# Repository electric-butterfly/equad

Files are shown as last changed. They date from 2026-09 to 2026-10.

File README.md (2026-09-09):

# eQuad

Electric conversion of a 2012 Suzuki King Quad 400 (LT-A400F), retaining the standard
shaft drivetrain and replacing the engine and CVT with a PMSM motor, a 26S2P lithium pack
and a Fardriver controller.

The vehicle keeps both differentials, both propeller shafts and the selectable 4WD front
end. An intermediate drive replaces the engine, transmission and transfer case, taking the
motor's output down to propeller-shaft speed and splitting it fore and aft.

## Duty

A working farm quad in Far North Queensland. It has to tow, it will spend its life in
heat, and it is the first build of a conversion approach intended to carry across to other
off-road machines — quads, side-by-sides, buggies and small ride-ons.

That duty sets the priorities: continuous thermal capability and low-speed tractive effort
ahead of top speed, and a battery box design that repeats across builds rather than one
tailored to this frame alone.

**Top speed target is 60–70 km/h flat out.** Range modes come from the controller's three
digital speed inputs, which select between three parameter maps.

---

## Current focus — the modelling workflow

The immediate objective is not the vehicle. It is a repeatable, AI-supported 3D modelling
workflow that turns a scan of the donor quad into Fusion or SolidWorks models good enough
to hand a fabricator for final manufacturing design and setup.

Everything downstream depends on it. The intermediate drive, the battery and switchgear
boxes and the cooling system are all packaging problems on a machine whose geometry exists
only as a scan and a set of physical parts.

### The workflow, end to end

| Stage | Output |
| --- | --- |
| Capture | Artec scan of the complete vehicle (held) |
| Condition | Decimated, hole-filled mesh aligned to a vehicle datum |
| Reference | Mesh imported to CAD as a non-parametric backdrop |
| Interface capture | Parametric solids for mounting faces, frame rails and shaft flanges only |
| Design | New assemblies modelled against those interfaces |
| Handover | STEP plus dimensioned drawings, toleranced at the interfaces |

The scan is a backdrop, not a model. Only the surfaces a new part actually touches get
reverse-engineered into parametric geometry; the rest stays as mesh. That keeps the CAD
tractable and puts the tolerance discussion exactly where the fabricator needs it.

### Where AI carries load

- Mesh conditioning and datum alignment driven as scripted, repeatable steps rather than
  by hand in a GUI.
- Fusion API (Python) and SolidWorks API scripting to generate parametric features from
  captured interface geometry.
- Maintaining a single parameter table — ratios, envelopes, centre distances — as the one
  source of truth that both the CAD and this repository read from.
- Extracting and cross-checking dimensions against the supplier datasheets and the Suzuki
  shop manual, so any number in the model can be traced back to a document.

### Source geometry

Two Artec exports of the complete vehicle:

| File | Triangles | Size |
| --- | --- | --- |
| King Quad 400 Full Res.stl | 35 074 344 | 1.75 GB |
| King Quad 400 Low Res.stl | 1 844 914 | 92.2 MB |

Both are valid binary STL. The low-res mesh bounds a volume of 2093 × 1850 × 1125 mm,
which places it in millimetres at roughly life size against the vehicle's 2060–2160 mm
overall length and 1145 mm overall height.

The 1850 mm intermediate extent is well beyond the vehicle's 1200 mm overall width, so the
mesh is either rotated within its own frame or carries geometry captured beyond the quad
itself. Establishing a vehicle datum — and trimming to it — is the first stage of
conditioning.

Scan data lives in the project drive, not in this repository.

### Design packages

**Intermediate drive.** The load-bearing item. A single cross-shaft carrying output stubs
for the standard front and rear propeller shafts, driven from the motor, with tension taken
up by the motor mount. It has to reproduce the propeller shaft spline interfaces exactly,
set the centre distance for the chosen drive, and shed mud and debris.

Chain is the working assumption over toothed belt, on the fabricator's recommendation:
higher torque capacity, tolerant of an unsealed housing, smaller footprint, durable in a
rugged environment, and length adjustable and breakable for installation. The costs are
noise, lubrication and maintenance, and higher rotating inertia.

The shop manual gives service data for the output shafts — bevel gear backlash
0.03–0.15 mm, output and bevel gear nuts at 100 N·m — but no spline or flange dimensions.
Those interfaces have to come from measurement of the parts and from the scan.

**Battery boxes.** Two packs in an inverted V, one either side, leaving a channel down the
centre for the front propeller shaft. The channel doubles as the cooling duct, so the two
packages are dimensionally coupled — cells set the wall angle, and the duct sets the
minimum clear width between them.

The inverted V also puts pack mass low and outboard, which suits a machine that tows, and
it splits the pack into two enclosures that can carry their own contactor and fuse. Whether
the volume is really there is a scan question, not a paper one.

**Controller box.** An aluminium box in the fuel tank position holding the controller, the
AC and DC terminations and control wiring, with its base doubling as the duct roof and
heatsink. The relay-version BMS drives remote contactors, so no main current passes through
box electronics.

Sealing it against mud and water means everything inside loses its own path to air. Busbar
and terminal joint losses at pack current are tens of watts with nowhere to go but the base
plate already carrying the controller. Solar gain on an aluminium box in the open in FNQ is
worth a thought too.

**Switchgear box.** Separate. Contactors, fuses, fuse holders, pre-charge and the DC-DC
converter. Two packs with two-pole isolation each accounts for the four main contactors;
pre-charge needs a fifth, and six were purchased.

**Cooling.** Forced air. The motor is air-cooled and is the continuous bottleneck; the
controller is natural-convection cooled and fully potted. Neither will look after itself
under a sustained tow in the heat, and natural airflow at crawl speed is close to zero —
which is exactly when the load is highest.

The donor supplies most of the hardware. It carries a cooling fan on a bracket at the oil
cooler, and the LT-A400 also has moulded V-belt cooling ducts running from a high intake
down into the centre of the machine — the same channel the battery box is aiming at, and
already routed the way it is because grass seed and mud are the enemy of a low intake.
Both the fan mounting and the duct geometry are in the scan and are worth capturing rather
than redesigning.

Fan control comes from the motor's KTY83-122 probe and controller temperature, not the
stock thermo-switch, which closes at about 120 °C engine oil temperature — at or past the
motor's own working ceiling. Run-on after shutdown matters more on an air-cooled motor than
it did on the engine, because a hot motor with the machine stopped has no airflow at all.

### Duct and fan sizing

Design point: 35 °C ambient at 750 m, which gives an air density of 1.047 kg/m³. Air enters
at the centre channel, passes the controller, then the motor, and rejects to the rear.
Controller first is correct — it is the temperature-sensitive item, rated to 55 °C ambient
against a 120 °C motor.

| Duty | Motor loss | Controller loss | Total |
| --- | --- | --- | --- |
| 4.0 kW shaft | 444 W | 91 W | 535 W |
| 7.5 kW shaft | 833 W | 170 W | 1003 W |

Carrying 1000 W on a 15 K air temperature rise needs **64 L/s, about 140 cfm**. The lighter
duty needs 34 L/s. Duct section then sets velocity, and velocity sets both heat transfer
and fan work:

| Duct | Velocity | Pressure drop | Fan power at 12 V |
| --- | --- | --- | --- |
| 200 × 120 mm | 2.7 m/s | 30–56 Pa | 1.2 A |
| 150 × 100 mm | 4.3 m/s | 76–143 Pa | 3.0 A |
| 120 × 80 mm | 6.7 m/s | 186–349 Pa | 7.4 A |

**150 × 100 mm is the sensible compromise.** Wider and the air moves too slowly to pick the
heat up; narrower and fan power climbs faster than the heat transfer it buys.

The fan has to hold pressure, not just move free air. At 64 L/s against 150 Pa the air
power is only 9 W, but at realistic fan efficiency that is around 3 A at 12 V — comfortable
against the 30 A DC-DC. A centrifugal automotive cabin blower or a high-static axial suits;
a cheap muffin-style axial stalls well below this pressure. Whether the donor's oil-cooler
fan is pressure-capable enough is not established.

### The controller needs fins

The controller is a sealed, potted brick. Its heat leaves through the aluminium baseplate,
189 × 122 mm, so it bolts baseplate-down onto whatever does the rejecting. The potted body
itself is not a useful radiating surface, and putting the brick in the airstream achieves
little beyond obstructing the duct.

Mounting it to the duct wall does not work. At 4.3 m/s the inner face sees about
18 W/m²K and the outer face sits in still air under the machine at perhaps 6 W/m²K. On a
150 mm wide duct that yields:

| Wall panel | Wetted area | Heat rejected |
| --- | --- | --- |
| 150 × 300 mm | 0.045 m² | 25 W |
| 150 × 400 mm | 0.060 m² | 33 W |
| 150 × 600 mm | 0.090 m² | 49 W |

Against 170 W the required bare wall is 0.31 m² — a duct 2.1 m long. Not available.

A plate spreads heat poorly at that scale, too. Acting as a fin, a 6 mm aluminium plate
runs at 73% efficiency 200 mm from the source and 45% at 400 mm; 15 mm plate reaches 87%
and 64%. The far corners of a large plate contribute much less than their area suggests.

### Switchgear box as the heatsink

The arrangement: an aluminium box in the fuel tank position, controller bolted flat to the
box base, and that base forming the roof of the duct. Welded sheet strips hang down from it
into the airstream. The tank position gives roughly the right envelope — the stock tank is
16.0 L including 2.9 L reserve — and the box also carries the BMS and terminals.

Welded strips suit this better than an extrusion. Thick strips conduct well, so fin
efficiency stays high, and the wide pitch that welding forces keeps pressure drop and
fouling down — both of which matter more here than packing density.

Fin efficiency, weldable alloy at about 150 W/m·K:

| Strip thickness | 40 mm high | 60 mm high | 80 mm high |
| --- | --- | --- | --- |
| 3 mm | 0.96 | 0.91 | 0.86 |
| 4 mm | 0.97 | 0.93 | 0.89 |
| 6 mm | 0.98 | 0.96 | 0.92 |

Sizing with 4 mm strips at 20 mm pitch — seven fins across the 150 mm duct:

| Fin height | Length | Wetted area | Rejected | Duct blockage |
| --- | --- | --- | --- | --- |
| 40 mm | 300 mm | 0.199 m² | 108 W | 7% |
| 40 mm | 400 mm | 0.266 m² | 144 W | 7% |
| 60 mm | 300 mm | 0.272 m² | 147 W | 11% |
| 60 mm | 400 mm | 0.363 m² | 196 W | 11% |

**60 mm strips over 350–400 mm covers the 170 W worst case with margin**, at about 11%
blockage — a small velocity rise and a modest pressure penalty.

The base plate has to spread heat from the controller's 189 × 122 mm footprint out to the
far fins. At 8–10 mm it runs 0.82–0.85 efficient 150 mm beyond the controller; 6 mm drops
to 0.78. Ten millimetres is the sensible base, and it welds and stiffens well. Fins
directly beneath the controller work at full effect, so they earn their length there first.

**Open input:** the manual gives the controller a working temperature of −30 to +55 °C
without saying whether that is ambient or baseplate. If it is ambient and the baseplate may
run to 85 °C, the temperature difference goes from 30 K to 50 K and the required area falls
from 0.39 m² to 0.24 m². That single answer changes the heatsink by a factor of 1.6 and is
worth getting from Fardriver before the switchgear box is drawn.

The motor is the easier problem because it tolerates a much larger temperature difference,
but at 0.3–0.6 m² of case area it is still marginal at the 7.5 kW duty. If the case does
not provide that, the practical continuous rating in this installation is nearer 4 kW than
7.5 kW — which is a reason to gear for tractive effort rather than speed.

**Layout.** Mass distribution, ground clearance and service access across the whole
vehicle.

---

## Vehicle

2012 Suzuki King Quad 400, LT-A400F — automatic (V-belt CVT), 2-speed transfer with
reverse, selectable 4WD, shaft drive front and rear.

| | |
| --- | --- |
| Overall length | 2060–2160 mm |
| Overall width | 1200 mm |
| Overall height | 1145 mm |
| Wheelbase | 1220 mm |
| Front / rear track | 880 / 900 mm |
| Ground clearance | 250 mm |
| Seat height | 840 mm |
| Dry mass | 252–275 kg |
| Tyres | AT25 × 8-12 front, AT25 × 10-12 rear |

Stock driveline ratios, from the shop manual:

| | LT-A400 (auto) |
| --- | --- |
| Primary (CVT) | 2.938 – 0.813 variable |
| Secondary | 2.730 (42/19 × 21/17) |
| Final drive, front and rear | 3.600 (36/10) |
| Transfer — low / high / reverse | 2.500 / 1.375 / 2.125 |

The conversion deletes the engine, CVT and transfer case. Only the 3.600 final drive
survives, and reverse moves to the controller and a DNR selector.

## Drivetrain sizing

The V3 motor carries a 1:2.35 reduction inside it, so the motor's rotor speed and the
speed presented to the intermediate drive are not the same number. Ratios below are stated
from the rotor.

| | |
| --- | --- |
| Motor maximum speed | 7000 rpm |
| Internal gearbox | 2.350 |
| Motor output shaft, maximum | 2979 rpm |
| Motor output sprocket | 428 chain, 14–16 teeth |
| Final drive | 3.600 |
| Rolling circumference | 1.995 m (AT25, 635 mm diameter) |

### Selecting the intermediate ratio

Road speed and tractive effort trade directly against each other through this one ratio.
Candidates on standard 428 sprockets, against the 60–70 km/h target:

| Drive | Driven | Ratio | Top speed | Peak effort | Continuous effort |
| --- | --- | --- | --- | --- | --- |
| 15 | 21 | 1.400 | 70.7 km/h | 2381 N | 508 N |
| 14 | 20 | 1.429 | 69.3 km/h | 2430 N | 518 N |
| 15 | 22 | 1.467 | 67.5 km/h | 2494 N | 532 N |
| 14 | 21 | 1.500 | 66.0 km/h | 2551 N | 544 N |
| 15 | 23 | 1.533 | 64.6 km/h | 2608 N | 556 N |
| 14 | 22 | 1.571 | 63.0 km/h | 2673 N | 570 N |
| 15 | 24 | 1.600 | 61.9 km/h | 2721 N | 581 N |
| 14 | 23 | 1.643 | 60.3 km/h | 2794 N | 596 N |

Effort figures are total at the axles on a 635 mm tyre, from 150 N·m peak and 32 N·m
continuous at the motor output. The band is narrow — 60 km/h buys only 17% more tractive
effort than 70 km/h — so the choice can be made on packaging and sprocket availability
rather than agonised over. Something near 14/21 or 15/22 sits mid-target.

For reference, the originally sketched 2:1 gives 49.5 km/h with 3402 N peak.

### Control mapping

Three digital speed inputs select three parameter maps. The intent is distinct throttle
and response curves per map — a genuine low-speed crawler mode with a softened throttle
curve and a lower ramp rate, a general working map, and an unrestricted map.

Crawl control was the part of the deleted low range that mattered most day to day, and
mapping recovers it. What mapping cannot recover is thermal headroom under sustained load,
which stays a function of the mechanical ratio alone. That keeps sustained towing duty —
not crawl feel — as the argument for the lower end of the ratio band.

The wiring inputs are confirmed in the controller manual: high gear / low gear, reverse and
cruise. Which parameters are per-map rather than global is not documented in the material
held, and it needs establishing before the crawler map can be specified.

## Powertrain

**Motor** — SIAECOSYS QS138 90H V3, PMSM mid-drive with integrated single-stage gearbox.

| | |
| --- | --- |
| Rated voltage | 72 V |
| Rated power | 4000 W |
| Peak power | 11–13.5 kW |
| Motor speed, rated / maximum | 4800 / 7000 rpm |
| Internal gear ratio | 1:2.35 |
| Output | 428 chain sprocket |
| Torque at output, rated / maximum | 32 / 150 N·m |
| Rated current | 60 A |
| Maximum bus current | 200 A |
| Maximum efficiency | 90–93% |
| Magnet | 90 mm, 5 pole pairs |
| Sensor | Single hall set |
| Mass | 14.5–16.6 kg |
| Protection | IP67 |

Reseller figures vary — continuous power is quoted anywhere from 4 kW to 7.5 kW and peak
from 11 kW to 20 kW. The torque figures are internally consistent with the gearbox ratio,
so they are the ones to design against.

**Controller** — Fardriver ND961000, NS48 family.

| | |
| --- | --- |
| Rated voltage | 96 V |
| Bus current | 450 A |
| Phase current | 1000 A |
| Rated power | 5.0–9.0 kW |
| Envelope | 189 × 122 × 54.7 mm |
| Cooling | Natural convection, fully potted |
| Operating temperature | −30 to +55 °C |
| Interfaces | CAN, RS485, one-wire, analogue |

**Battery** — CALB L148N58A prismatic lithium-ion, 26S2P.

| Cell | |
| --- | --- |
| Nominal capacity | 58 Ah at 1C |
| Working voltage | 2.75–4.35 V above 0 °C |
| Internal resistance | 0.60–0.80 mΩ at 1 kHz, 70% SOC |
| Continuous discharge | 1C (58 A) at 20–40 °C |
| Pulse discharge | 450 A for 10 s below 50 °C |
| Recommended SOC window | 5–97% |
| Mass | 926 ± 20 g |
| Envelope | 148.24 × 26.66 × 105.9 mm |
| Terminal spacing | 110.6 mm |
| Case | Aluminium alloy |

| Pack (26S2P) | |
| --- | --- |
| Nominal | 96.2 V |
| Range | 71.5–113.1 V |
| Capacity | 116 Ah |
| Energy | 11.16 kWh, 10.04 kWh at 90% DoD |
| Continuous | 116 A, 11.2 kW |
| Cell mass | 48.2 kg for 52 cells |

Charge current is temperature-limited: 1.2C peak at 20–45 °C, falling to 0.2C at 0–10 °C
and disallowed below −20 °C. Regenerative braking is limited by state of charge as well as
temperature — 5C for 10 s at 80% SOC and 20–40 °C, and not permitted at all above 95% SOC.
Both constraints belong in the BMS configuration, not only in the documentation.

**BMS** — ANT 21S–30S, 24–112 V, 400 A / 1000 A, with CAN customisation.

**Switchgear** — TE Kilovac EV200HAANA sealed contactors, SPST-NO, 500 A, 9–36 V DC coil.
Littelfuse JLLN Class T fuses with LSCR holders.

**Auxiliary** — 48–120 V to 12 V, 30 A, 400 W DC-DC converter.

**Charging** — two chargers held. Output voltage and current are unconfirmed and no
charger appears in the BOM.

## CAN architecture

The Fardriver CAN protocol is SAE J1939-21 over CAN 2.0B at 500 kbit/s, PDU2 format.

| Node | Source address |
| --- | --- |
| BMS | 1 |
| Motor controller | 2 |
| Instrument | 3 |
| Central control | 4 |

Termination is not uniform across the bus. The controller carries its own 120 Ω and a
non-isolated transceiver; the instrument needs an isolated transceiver and provides a
120 Ω; the BMS provides no resistor and references the bus to battery negative. The harness
design has to respect that asymmetry.

## Reference library

Held in the project drive alongside the scans:

- Suzuki King Quad 400 LT-A400F / LT-F400F shop manual, 2008–2014
- CALB L148N58A cell specification and dimensioned drawing, plus superseded cell
  candidates from CATL, CALB and JMRI
- Fardriver controller manual, tuning guide, NS48 and S60 datasheets, CAN18 protocol
- TE Kilovac contactor and Littelfuse JLLN datasheets
- EB-Quad BOM and gear ratio calculator
- Drive pulley concept sketch
- Supplier contracts and invoices

## Open engineering questions

**Cell continuous rating.** The BOM records these cells at 8C and 268 A continuous. The
datasheet allows 1C continuous — 58 A per cell, 116 A at pack level — with 8C available
only as a 450 A, 10-second pulse. The supplier listing reads the same way, so the 8C
figure is a misreading rather than a supplier claim.

It does not force a redesign. The motor is the continuous bottleneck, not the pack:

| Limit | Current at 96.2 V | Power |
| --- | --- | --- |
| Motor, continuous | 42–78 A | 4.0–7.5 kW |
| Pack, continuous (1C) | 116 A | 11.2 kW |
| Motor, maximum bus | 200 A | 19.2 kW |
| Pack, 10-second pulse | 900 A | — |
| Controller bus limit | 450 A | 43.3 kW |

The pack comfortably outruns what the motor can absorb continuously, and its pulse
capability sits well above the motor's peak. What the 8C figure does need to change is the
BMS configuration — set discharge limits from the datasheet, not the BOM — and any future
sizing calculation that inherits it.

**Voltage margin.** The binding limit is the controller, not the fuse. The ND961000's peak
battery voltage is 115 V; a pack charged to 4.35 V per cell reaches 113.1 V — under two
volts of headroom. The JLLN fuse is the looser constraint at 125 V DC. Capping charge
voltage below 4.35 V per cell costs a little capacity and buys cycle life anyway, and is
the cheaper fix than dropping to 25S.

**Fuse sizing.** An 800 A element sits far above both the 450 A controller bus limit and
the 116 A cell limit, so it protects against a short circuit and nothing else. Overload
protection has to come from the BMS and controller.

**Contactor datasheet.** The parts held are EV200HAANA; the datasheet on file is for the
LEV200 series. The EV200 datasheet is the one to design the switchgear box against.

**Intermediate ratio.** Narrowed to 1.40–1.64 by the 60–70 km/h target, but not yet
fixed. The remaining input is packaging: sprocket diameters and the centre distance they
imply have to fit the space the engine vacates, which is a scan question. This is the
last drivetrain number the fabricator needs.

**Motor speed limit.** Rated voltage is 72 V; the pack is 96.2 V nominal and 113.1 V at
full charge. Speed scales with voltage, so at full charge the motor would run past its
7000 rpm mechanical ceiling before flux weakening is asked for. The controller's rpm limit
has to be set deliberately, not left at default.

**Thermal headroom.** The motor is air-cooled and it is the continuous bottleneck, on a
machine that tows in FNQ heat. Forced air is the plan; what is not yet settled is the duct
routing, whether the stock fan moves enough air for the new heat load, and how the
controller derates on temperature. All three want answering before the layout is fixed
rather than after the first hot tow.

**ANT CAN protocol.** The BMS was ordered with CAN customisation specifically to join the
J1939 bus, and the supplier confirmed they can provide the protocol document. It is not in
the reference library. Without it the BMS cannot be integrated, and the harness and dash
design cannot be closed out.

**Pre-charge.** Required. Two distinct inrush problems exist in this architecture and only
one of them is solved by matching pack voltages.

Matching the two packs before paralleling controls pack-to-pack circulating current, and
that plan is sound. It does nothing for the controller's DC bus capacitors, which sit at
zero volts every time the system is switched on regardless of how well the packs agree.
Closing a main contactor straight onto them is a capacitor charging event limited only by
loop resistance.

Peak inrush is set by loop resistance alone — capacitance governs how long it lasts, not
how high it goes. The pack's own internal resistance dominates the loop at 9.1 mΩ for
26S2P, from the cell datasheet's 0.6–0.8 mΩ:

| Added cable, contactor and ESR | Peak inrush |
| --- | --- |
| 5 mΩ | 8021 A |
| 10 mΩ | 5921 A |
| 20 mΩ | 3887 A |
| 40 mΩ | 2303 A |

Even with no external resistance at all the pack can only deliver 12 429 A, and holding
inrush to the contactors' 2000 A interrupt rating would need 56.5 mΩ of added loop —
six times the pack's own resistance, which a short heavy-cable HV loop will not provide.
The conclusion holds across the whole plausible range: making a main contactor onto a
discharged bus welds contacts, and not necessarily the first time, which is why the
omission surfaces late.

A resistor across one pack's main contactor, switched by a pre-charge contactor, fixes it.
Sequence is pre-charge, confirm bus voltage has risen to pack voltage, close the pack mains
onto an already-charged bus, then drop pre-charge. The second pack then closes onto a bus
already at its own voltage, which is where the manual voltage matching does its work.

**Sizing the resistor needs the bus capacitance, which is not published.** It is absent
from the controller manual, the NS48 datasheet and the reseller listings. It sets both the
pre-charge duration (5RC to 99%) and the pulse energy the resistor must absorb, which is
½CV² per closure regardless of resistor value. Measuring it settles both: charge the bus
through a known high resistance from a bench supply and time the rise to 63%.

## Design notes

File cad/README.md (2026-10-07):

# Battery box CAD

All parameters come from `params.toml`. Run every script from the repo root.

| Script | venv | Run order | What it builds |
|---|---|---|---|
| `cell.py` | `.venv-cad` | 1 | The cell and the 26-cell block; `--report` writes `cell-report.md` |
| `enclosure.py` | `.venv-cad` | 2 | The enclosure, lid, internals, fuse bay and cable exits |
| `assembly.py` | `.venv-cad` | 3 | Two boxes on the datum, motor placeholder, keep-out, `placement.json` |
| `clearance.py` | `.venv-mesh` | 4 | Placement evaluation, the sweep, section renders |
| `mounts.py` | `.venv-mesh` | 5 | Frame primitives within reach of the placed box |
| `viewer.py` | `.venv-cad` | 6 | `viewer.html` and `sam-battery-boxes.html` |
| `fusion_pack.py` | `.venv-cad` | 7 | `datum-marker.step` and `fusion-import.html` |

Every script resolves the repo root with `git rev-parse --show-toplevel`, loads `cad/params.toml`,
writes only to `data/cad/` and `docs/thrifty/2026-09-15-battery-boxes/artefacts/`, and refuses to
run if a named input is missing. `common.py` reads `freecad_cmd` from
`pipeline/config.local.toml` for the STEP round-trip check; no other script reads that file.

```
.venv-cad/Scripts/python cad/cell.py
.venv-cad/Scripts/python cad/enclosure.py
.venv-cad/Scripts/python cad/assembly.py
.venv-mesh/Scripts/python cad/clearance.py
.venv-mesh/Scripts/python cad/mounts.py
.venv-cad/Scripts/python cad/viewer.py
.venv-cad/Scripts/python cad/fusion_pack.py
```

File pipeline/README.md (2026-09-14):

# Pipeline

Condition, crop, segment and fit the King Quad scan against the vehicle datum. See
`docs/thrifty/2026-09-14-scan-pipeline/plan.md` section 4 for the full contract.

## Setup

1. Create the mesh venv and install its pins:
   ```
   python -m venv .venv-mesh
   .venv-mesh/Scripts/python -m pip install -r pipeline/requirements-mesh.txt
   ```
2. Install CloudCompare (`winget install --id CloudCompare.CloudCompare --exact`) and MeshLab
   (`winget install --id CNRISTI.MeshLab --exact`).
3. Copy `pipeline/config.example.toml` to `pipeline/config.local.toml` and fill in the absolute
   paths on this machine (scan files, `data_root`, `CloudCompare.exe`, `FreeCADCmd.exe`).
   `config.local.toml` is git-ignored.

## Stages

| Script | Written by | Purpose |
|---|---|---|
| `pipeline/condition.py` | WP-03 | Clean the full-res scan, remove the floor, align to the ISO 8855 vehicle datum, write decimations and `datum.json`. |
| `pipeline/crop.py` | WP-04 | Cut the six named regions from `pipeline/crops.toml` into per-region meshes, point clouds and silhouettes. |
| `pipeline/segment.py` | WP-05 | Run CloudCompare RANSAC on each region's point cloud and write a primitive table per region. |
| `pipeline/fit.py` | WP-06 | Refine each accepted primitive on full-resolution points and write `interfaces.json` with residuals. |

Each script loads `pipeline/config.local.toml` via `pipeline/common.py`, resolves `data_root`
against the repo root, and refuses to run if a required key or file is missing. Run from the mesh
venv:

```
.venv-mesh/Scripts/python pipeline/condition.py
.venv-mesh/Scripts/python pipeline/crop.py
.venv-mesh/Scripts/python pipeline/segment.py
.venv-mesh/Scripts/python pipeline/fit.py
```

Every script takes `--stage-only` flags as documented in its own `--help`, and writes nothing
outside `data_root` and `docs/thrifty/2026-09-14-scan-pipeline/artefacts/`.

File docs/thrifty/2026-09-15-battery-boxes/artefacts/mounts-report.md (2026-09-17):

104 frame primitives within 120 mm of a placed battery box.

| id | kind | box | face | distance mm | support | rms |
|---|---|---|---|---|---|---|
| engine-bay/cyl/148 | cylinder | right | inboard | 1.1 | 4723 | 0.97 |
| engine-bay/plane/046 | plane | left | inboard | 1.6 | 2088 | 0.24 | *calliper before drilling*
| tank-mounts/cyl/064 | cylinder | left | inboard | 1.8 | 7256 | 0.82 |
| duct-route/cyl/092 | cylinder | left | inboard | 2.8 | 29471 | 0.94 |
| engine-bay/plane/014 | plane | left | inboard | 3.5 | 3225 | 0.14 | *calliper before drilling*
| engine-bay/plane/031 | plane | right | inboard | 4.7 | 2490 | 0.25 | *calliper before drilling*
| engine-bay/plane/053 | plane | right | inboard | 5.8 | 1632 | 0.17 | *calliper before drilling*
| engine-bay/plane/015 | plane | left | rear | 5.9 | 4148 | 0.48 | *calliper before drilling*
| engine-bay/plane/032 | plane | right | outboard | 6.7 | 1630 | 0.19 | *calliper before drilling*
| engine-bay/plane/064 | plane | right | front | 6.7 | 1560 | 0.19 | *calliper before drilling*
| engine-bay/plane/037 | plane | left | front | 7.0 | 1662 | 0.16 | *calliper before drilling*
| engine-bay/plane/010 | plane | right | outboard | 8.7 | 5446 | 0.27 | *calliper before drilling*
| engine-bay/plane/011 | plane | left | outboard | 9.0 | 5085 | 0.18 | *calliper before drilling*
| duct-route/cyl/159 | cylinder | left | inboard | 11.0 | 3398 | 0.56 |
| tank-mounts/cyl/046 | cylinder | right | inboard | 12.3 | 13836 | 0.41 |
| engine-bay/cyl/107 | cylinder | left | inboard | 13.0 | 24932 | 0.77 |
| engine-bay/cyl/028 | cylinder | right | outboard | 13.1 | 26024 | 0.29 |
| rear-flange/cyl/015 | cylinder | right | outboard | 13.1 | 25956 | 0.33 |
| duct-route/cyl/071 | cylinder | right | outboard | 13.5 | 39433 | 0.80 |
| engine-bay/cyl/016 | cylinder | right | outboard | 16.5 | 69197 | 0.30 |
| duct-route/cyl/011 | cylinder | right | outboard | 16.6 | 72681 | 0.57 |
| tank-mounts/cyl/033 | cylinder | left | inboard | 17.7 | 23476 | 0.61 |
| duct-route/cyl/070 | cylinder | left | outboard | 18.1 | 39185 | 0.69 |
| engine-bay/plane/013 | plane | left | inboard | 18.8 | 3426 | 0.23 | *calliper before drilling*
| engine-bay/cyl/050 | cylinder | right | outboard | 19.5 | 20271 | 0.59 |
| rear-flange/cyl/035 | cylinder | right | front | 19.9 | 16052 | 0.89 |
| engine-bay/cyl/038 | cylinder | right | outboard | 21.9 | 49672 | 0.86 |
| duct-route/cyl/009 | cylinder | left | outboard | 22.1 | 105370 | 0.96 |
| duct-route/cyl/056 | cylinder | left | outboard | 22.3 | 16570 | 0.72 |
| duct-route/cyl/051 | cylinder | left | outboard | 22.3 | 68784 | 0.43 |
| engine-bay/cyl/085 | cylinder | right | outboard | 22.9 | 12657 | 0.98 |
| duct-route/cyl/094 | cylinder | left | outboard | 23.3 | 17668 | 0.90 |
| engine-bay/plane/030 | plane | right | lid | 23.9 | 2601 | 0.57 | *calliper before drilling*
| duct-route/cyl/044 | cylinder | right | outboard | 24.3 | 19682 | 0.72 |
| duct-route/cyl/022 | cylinder | right | outboard | 24.4 | 19068 | 0.49 |
| engine-bay/cyl/120 | cylinder | right | outboard | 24.7 | 46304 | 0.41 |
| tank-mounts/cyl/076 | cylinder | right | inboard | 24.8 | 6719 | 0.76 |
| engine-bay/cyl/041 | cylinder | left | inboard | 25.1 | 26198 | 0.98 |
| duct-route/cyl/043 | cylinder | right | outboard | 25.1 | 14177 | 0.48 |
| duct-route/cyl/027 | cylinder | left | outboard | 25.2 | 42893 | 0.49 |
| duct-route/cyl/059 | cylinder | left | outboard | 25.2 | 33489 | 0.12 |
| duct-route/cyl/032 | cylinder | left | front | 26.0 | 6945 | 0.75 |
| duct-route/cyl/103 | cylinder | left | inboard | 26.7 | 4494 | 0.40 |
| engine-bay/plane/035 | plane | left | rear | 26.8 | 1791 | 0.27 | *calliper before drilling*
| engine-bay/plane/039 | plane | right | lid | 27.1 | 3048 | 0.54 | *calliper before drilling*
| engine-bay/cyl/024 | cylinder | left | rear | 29.6 | 50320 | 0.20 |
| engine-bay/plane/009 | plane | left | outboard | 29.6 | 4437 | 0.15 | *calliper before drilling*
| engine-bay/plane/022 | plane | right | lid | 29.7 | 2835 | 0.36 | *calliper before drilling*
| engine-bay/plane/021 | plane | right | outboard | 30.0 | 2775 | 0.21 | *calliper before drilling*
| duct-route/cyl/042 | cylinder | right | front | 30.4 | 4429 | 0.93 |
| engine-bay/cyl/070 | cylinder | left | inboard | 32.3 | 14785 | 0.39 |
| tank-mounts/cyl/070 | cylinder | left | inboard | 34.5 | 15843 | 0.71 |
| engine-bay/cyl/138 | cylinder | right | inboard | 35.1 | 29500 | 0.39 |
| engine-bay/plane/019 | plane | right | front | 39.5 | 4835 | 0.93 | *calliper before drilling*
| duct-route/cyl/102 | cylinder | right | front | 40.3 | 4810 | 0.88 |
| duct-route/cyl/058 | cylinder | right | floor | 41.2 | 25759 | 0.37 |
| duct-route/cyl/048 | cylinder | left | front | 46.6 | 6203 | 0.84 |
| engine-bay/plane/025 | plane | right | rear | 47.9 | 2476 | 0.38 | *calliper before drilling*
| engine-bay/plane/016 | plane | left | rear | 48.4 | 3090 | 0.18 | *calliper before drilling*
| engine-bay/cyl/018 | cylinder | right | floor | 50.3 | 89594 | 0.37 |
| engine-bay/cyl/029 | cylinder | right | floor | 51.1 | 89922 | 0.57 |
| front-flange/cyl/048 | cylinder | left | rear | 51.6 | 68129 | 0.37 |
| engine-bay/cyl/013 | cylinder | right | floor | 54.7 | 131305 | 0.86 |
| duct-route/cyl/003 | cylinder | right | floor | 55.9 | 133590 | 0.72 |
| engine-bay/plane/001 | plane | left | front | 56.4 | 14975 | 0.34 | *calliper before drilling*
| engine-bay/plane/034 | plane | left | front | 56.9 | 2008 | 0.48 | *calliper before drilling*
| engine-bay/plane/028 | plane | right | front | 58.8 | 2547 | 0.24 | *calliper before drilling*
| engine-bay/plane/040 | plane | right | front | 60.7 | 1563 | 0.31 | *calliper before drilling*
| engine-bay/plane/027 | plane | right | front | 60.8 | 1982 | 0.30 | *calliper before drilling*
| engine-bay/plane/043 | plane | right | rear | 65.6 | 2463 | 0.57 | *calliper before drilling*
| engine-bay/plane/017 | plane | left | inboard | 68.1 | 3577 | 0.60 | *calliper before drilling*
| engine-bay/cyl/147 | cylinder | right | rear | 74.4 | 5920 | 0.67 |
| engine-bay/plane/007 | plane | right | front | 75.7 | 6759 | 0.30 | *calliper before drilling*
| engine-bay/cyl/056 | cylinder | right | front | 76.3 | 27356 | 0.95 |
| rear-flange/cyl/007 | cylinder | right | front | 76.6 | 23854 | 0.54 |
| rear-flange/cyl/009 | cylinder | left | front | 78.0 | 27002 | 0.88 |
| engine-bay/cyl/020 | cylinder | left | front | 79.7 | 88221 | 0.99 |
| tank-mounts/cyl/009 | cylinder | right | inboard | 80.6 | 98132 | 0.88 |
| engine-bay/plane/029 | plane | right | lid | 82.3 | 2106 | 0.16 | *calliper before drilling*
| engine-bay/plane/054 | plane | right | lid | 86.4 | 1686 | 0.09 | *calliper before drilling*
| engine-bay/plane/024 | plane | right | front | 87.7 | 2889 | 0.17 | *calliper before drilling*
| engine-bay/plane/020 | plane | left | front | 88.1 | 2721 | 0.28 | *calliper before drilling*
| engine-bay/plane/036 | plane | right | rear | 89.3 | 1817 | 0.34 | *calliper before drilling*
| duct-route/cyl/007 | cylinder | right | inboard | 89.6 | 88571 | 0.81 |
| engine-bay/plane/033 | plane | left | front | 91.2 | 1931 | 0.20 | *calliper before drilling*
| rear-flange/cyl/014 | cylinder | right | front | 92.2 | 71436 | 0.62 |
| duct-route/cyl/015 | cylinder | left | inboard | 94.9 | 84561 | 0.91 |
| engine-bay/plane/061 | plane | left | lid | 97.9 | 1521 | 0.66 | *calliper before drilling*
| engine-bay/cyl/004 | cylinder | left | rear | 102.7 | 99050 | 0.51 |
| duct-route/cyl/031 | cylinder | left | rear | 105.5 | 117657 | 0.83 |
| engine-bay/cyl/014 | cylinder | right | rear | 106.3 | 78150 | 0.21 |
| engine-bay/plane/005 | plane | left | inboard | 106.8 | 5679 | 0.15 | *calliper before drilling*
| duct-route/cyl/024 | cylinder | left | rear | 108.4 | 51173 | 0.42 |
| rear-flange/cyl/060 | cylinder | right | front | 111.1 | 22287 | 0.48 |
| tank-mounts/cyl/114 | cylinder | right | inboard | 111.9 | 25376 | 0.50 |
| front-flange/cyl/010 | cylinder | right | rear | 112.8 | 107573 | 0.32 |
| rear-flange/cyl/069 | cylinder | left | front | 112.9 | 18714 | 0.51 |
| engine-bay/cyl/035 | cylinder | right | inboard | 114.4 | 46128 | 0.24 |
| tank-mounts/cyl/043 | cylinder | left | inboard | 115.5 | 42661 | 0.32 |
| engine-bay/plane/002 | plane | left | inboard | 115.8 | 13127 | 0.38 | *calliper before drilling*
| engine-bay/cyl/072 | cylinder | left | inboard | 115.8 | 40069 | 0.45 |
| duct-route/cyl/008 | cylinder | right | inboard | 117.3 | 72471 | 0.44 |
| duct-route/cyl/023 | cylinder | right | rear | 118.3 | 33475 | 0.78 |
| duct-route/cyl/006 | cylinder | left | inboard | 119.5 | 82146 | 0.36 |

The mounting concept: two locating pins on each box floor engaging bushes on brackets from the lower rails, and two tensioners at the top, inboard, pulling the box down onto the pins and reached from above so their mechanism is out of the mud. Bracket design is Sam's. The planes in the table were fitted by RANSAC at 0.15-0.35 mm RMS but did not pass the pipeline's refinement threshold (section 5.1); each row that is a plane carries the note "calliper before drilling".

Section 5.1's four named engine-mount planes:
- `engine-bay/plane/001` (support 14975, rms 0.34): 56.4 mm from the left box, nearest face front.
- `engine-bay/plane/007` (support 6759, rms 0.30): 75.7 mm from the right box, nearest face front.
- `engine-bay/plane/010` (support 5446, rms 0.27): 8.7 mm from the right box, nearest face outboard.
- `engine-bay/plane/011` (support 5085, rms 0.18): 9.0 mm from the left box, nearest face outboard.

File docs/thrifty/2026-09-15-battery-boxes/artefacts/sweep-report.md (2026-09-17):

This sweep tests the frame, the placeholder motor and the propeller-shaft keep-out only; plastics, foot boards, tank and seat are not in the scan.

Grid: 525 placements, 0 pass.

| X | lean | feasible Y | feasible Z | best min_frame |
|---|---|---|---|---|
| 693.2 | 72.0 | - | - | none feasible |
| 693.2 | 77.0 | - | - | none feasible |
| 693.2 | 82.0 | - | - | none feasible |
| 693.2 | 87.0 | - | - | none feasible |
| 693.2 | 92.0 | - | - | none feasible |
| 743.2 | 72.0 | - | - | none feasible |
| 743.2 | 77.0 | - | - | none feasible |
| 743.2 | 82.0 | - | - | none feasible |
| 743.2 | 87.0 | - | - | none feasible |
| 743.2 | 92.0 | - | - | none feasible |
| 793.2 | 72.0 | - | - | none feasible |
| 793.2 | 77.0 | - | - | none feasible |
| 793.2 | 82.0 | - | - | none feasible |
| 793.2 | 87.0 | - | - | none feasible |
| 793.2 | 92.0 | - | - | none feasible |

No placement in the swept grid passes all three tests.

[placement] defaults (x=743.2, y=39.2643, z=440.4765, lean_deg=82.0) are not a grid point in this sweep, so no exact-match row exists; see the nearest grid rows above.

Motor placeholder vs frame (not part of pass, evaluated once): min_frame=0.07 mm, points inside=41066.

chamfer would not help: not evaluated in this run.

Nothing in this grid clears the frame - every one of the 525 placements has real frame points
inside the box (inside_frame never reached 0). The least-bad point found, used for the
section-*-best.png renders below, is x=793.2, y=-50.0, z=465.0, lean=87.0: min_frame=0.56mm,
inside_frame=15580 points, min_motor=178.8mm, min_keepout=0.012mm. This is not a fit; it is the
smallest measured intrusion in the swept neighbourhood, shown so the owner can see how close
"close" actually is.

Section renders: section-yz-default.png, section-xz-default.png, section-xy-default.png (the
committed [placement] defaults); section-yz-best.png, section-xz-best.png, section-xy-best.png
(the least-bad point above).

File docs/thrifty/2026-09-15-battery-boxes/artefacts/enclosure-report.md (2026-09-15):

# Enclosure report

## Parameters used
| Section | Key | Value |
|---|---|---|
| enclosure | internal | [460.0, 300.0, 200.0] |
| enclosure | sheet | 3.0 |
| enclosure | lid_face | +Z |
| enclosure | lid_inset | 15.0 |
| enclosure | lid_bolt_d | 6.5 |
| enclosure | lid_bolt_pitch_max | 60.0 |
| enclosure | end_plate | 6.0 |
| enclosure | partition | 3.0 |
| enclosure | compression_plate | 6.0 |
| enclosure | compression_wall | outboard |
| enclosure | compression_pairs | 5 |
| enclosure | compression_rows_z | [30.0, 75.0] |
| enclosure | compression_screw_d | 8.0 |
| enclosure | compression_travel_min | 10.0 |
| enclosure | chamfer_front_top | 0.0 |
| electrical | fuses_per_box | 2 |
| electrical | fuse_envelope | [90.0, 45.0, 60.0] |
| electrical | headroom | 60.0 |
| electrical | cable_exit_face | inboard |
| electrical | cable_exit_d | [20.0, 20.0, 25.0] |
| electrical | cable_exit_z | 160.0 |

## Y layout
| Element | Y low | Y high |
|---|---|---|
| end plate | -150.0 | -144.0 |
| fuse bay | -144.0 | -114.34 |
| partition | -117.34 | -114.34 |
| compression plate | 119.94 | 125.94 |
| stack length | 263.94 | |
| travel | 24.060000000000002 | |

## Front-column spacer - finding
Section 4.5 specifies a spacer of thickness `p - partition` between the front column's last cell and the compression plate. The rows produced by `cell.block()` (and section 4.4's own worked numbers, e.g. the 24.06 mm travel figure) show the front column's last cell is already flush with the 9-cell columns' last cell - both are positioned by the same `y0 + p*slot` formula at slot = n_max - 1. The computed gap here is 0.0 mm, not `p - partition` (26.66 mm). Building the literal-thickness block would overlap the compression plate, which spans the full cavity width. No spacer solid is built; box.step therefore has 7 solids (not the 8 the done-when criterion names), and box-full.step has 33 (not 34). Logged as a finding for the owner, not fixed by guessing at intent.

## Hole tables
Lid bolt holes: 26
Grub-screw holes: 10 (5 stations x 2 Z rows), through the outboard wall
Cable exit holes: 3, through the inboard wall

## Fuse envelopes
2 envelopes, overrun = -80.0 mm (no overrun)

## Interference table
| A | B | Intersection volume (mm3) |
|---|---|---|
| body | lid | 0 |
| body | end_plate | 0 |
| body | partition | 0 |
| body | compression_plate | 0 |
| body | fuse_0 | 0 |
| body | fuse_1 | 0 |
| body | block | 0 |
| lid | end_plate | 0 |
| lid | partition | 0 |
| lid | compression_plate | 0 |
| lid | fuse_0 | 0 |
| lid | fuse_1 | 0 |
| lid | block | 0 |
| end_plate | partition | 0 |
| end_plate | compression_plate | 0 |
| end_plate | fuse_0 | 32400.0 |
| end_plate | fuse_1 | 32400.0 |
| end_plate | block | 0 |
| partition | compression_plate | 0 |
| partition | fuse_0 | 16200.0 |
| partition | fuse_1 | 16200.0 |
| partition | block | 0 |
| compression_plate | fuse_0 | 0 |
| compression_plate | fuse_1 | 0 |
| compression_plate | block | 0 |
| fuse_0 | fuse_1 | 0 |
| fuse_0 | block | 50436.000000000015 |
| fuse_1 | block | 35977.68000000001 |

## Headroom check
needed = 165.9, internal_z = 200.0, OK

## box-shell.stl
bbox 466.0 x 306.0 x 206.0, 12 triangles, reimport is_manifold = True

## STEP round-trip checks
freecad: 7 solids, 3186335.6216923 mm3 (build123d: 7 solids, 3186335.6216923017 mm3) OK
freecad: 33 solids, 13764437.700272448 mm3 (build123d: 33 solids, 13764437.70027245 mm3) OK

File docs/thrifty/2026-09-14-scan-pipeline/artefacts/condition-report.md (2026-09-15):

# Condition report

Faces: loaded 35074344, after fragments 35027805, after floor 31097206.

## Datum agreement against artefacts/datum-reference.json

Axis angle differences (deg): X 0.014, Y 0.047, Z 0.048 (accept under 0.5).
Translation differences (mm): [0.36, 0.06, 0.02] (accept under 5).

## Floor and symmetry

Floor: inliers fraction 0.1609, RMS 1.209 mm.
Symmetry: rotation from PCA 11.617 deg, final fitness 0.5389, final RMSE 3.177 mm.

## Rear axle housing

Left: r=24.35 y=273.0 z=296.8 rms=0.76
Right: r=25.42 y=-265.4 z=300.7 rms=0.75
X span between sides: 0.58 mm.

## Renders

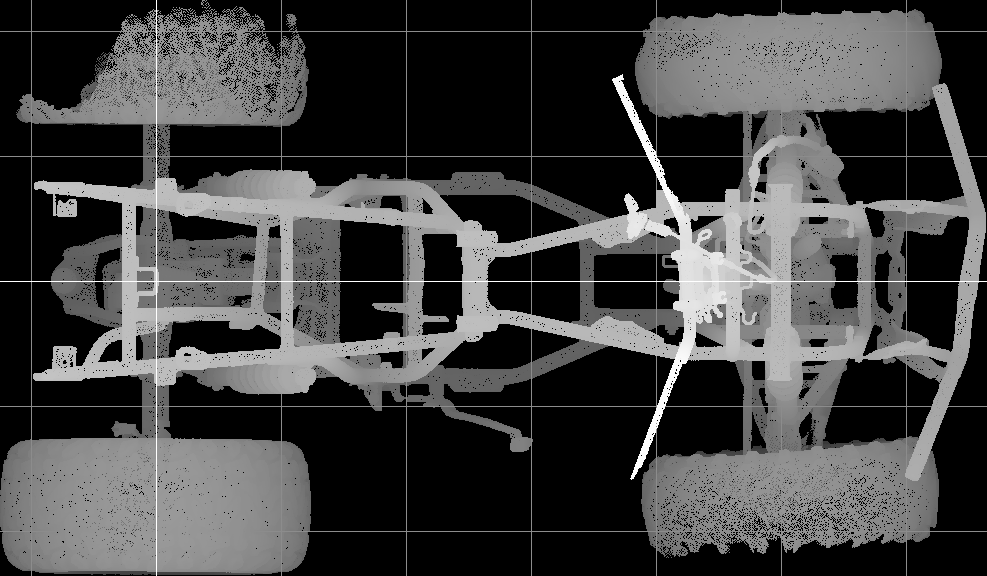
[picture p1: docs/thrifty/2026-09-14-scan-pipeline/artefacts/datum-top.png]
top


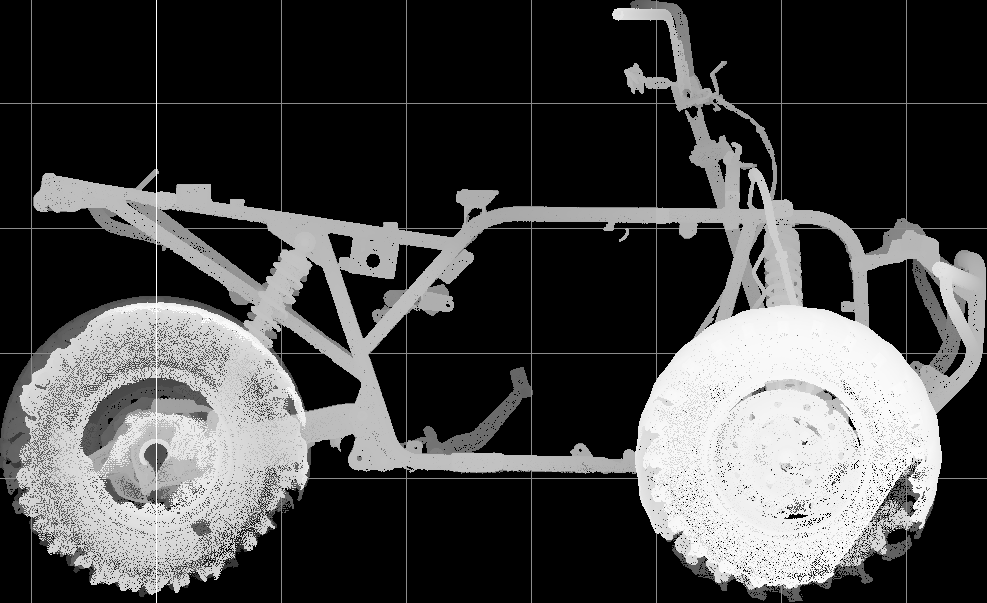
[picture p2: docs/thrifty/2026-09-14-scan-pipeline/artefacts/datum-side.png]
side


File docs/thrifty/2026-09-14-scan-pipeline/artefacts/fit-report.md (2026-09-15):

# Fit report — full-resolution refinement of RANSAC primitives

Per plan section 4.6. Candidates are RANSAC primitives that pass the section 4.5 acceptance rule
(cylinder: radius in a `tube_radii_mm` bracket and RANSAC rms under 1.2 mm; plane: RANSAC rms under
0.6 mm and support over 500). Each candidate is refined on full-resolution crop points within 3 mm
of the RANSAC surface (cylinders additionally bounded to the RANSAC primitive's own axial extent,
so the fit is not pulled in by unrelated points sharing the same infinite axis and radius). A
candidate is accepted when its refined rms is under 1.0 mm (cylinder) or 0.5 mm (plane); otherwise
it is written with `accepted: false` and a reason.

`tube_radii_mm` used: `[[11, 16], [17, 20], [22, 26], [26, 29]]` — the owner's
`pipeline/config.local.toml` extends the plan's default with a 26–29 mm bracket to admit the
rear-axle housing's left side. `CYLINDER_ACCEPT_RMS_MAX` is 1.0 mm in this run (`pipeline/fit.py`),
raised from the plan's original 0.8 mm. Neither change is reproducible from a fresh clone without
also setting `tube_radii_mm` locally, since `config.local.toml` is git-ignored by design.

## Per-region counts

| Region | Candidates | Accepted | Rejected |
|---|---|---|---|
| engine-bay | 206 | 32 | 174 |
| tank-mounts | 118 | 37 | 81 |
| front-flange | 142 | 26 | 116 |
| rear-flange | 85 | 11 | 74 |
| duct-route | 167 | 46 | 121 |
| rear-axle | 173 | 21 | 152 |
| **Total** | **891** | **173** | **718** |

## Rear-axle housing rows, in full

The two axle-housing cylinders identified by support are `rear-axle/cyl/001` (right side) and
`rear-axle/cyl/003` (left side).

| id | RANSAC radius | RANSAC support | Candidate? | Refined radius | Refined support | Refined rms | Accepted |
|---|---|---|---|---|---|---|---|
| rear-axle/cyl/001 | 24.97 mm | 21407 | yes | 25.601 mm | 79603 | 0.219 mm | true |
| rear-axle/cyl/003 | 27.03 mm | 24117 | yes (26–29 mm bracket) | 25.921 mm | 106842 | 1.940 mm | **false — refined rms 1.940 mm >= 1.0 mm** |

Widening the bracket got `cyl/003` into refinement, but it does not resolve to a clean cylinder:
its refined rms (1.940 mm) is well above even the relaxed 1.0 mm threshold, despite 106,842
supporting points. This is not a threshold or bracket problem — the real surface at that location
does not fit a constant-radius cylinder as well as the coarser RANSAC-stage estimate suggested,
which points to a physical feature near the housing (a flange, weld, or step) rather than a fitting
artefact. Confirming this needs a calliper or an individual rescan of the housing, not a further
threshold change.

## Ten worst residuals across all regions

| Region | id | Kind | Refined rms (mm) | p95 (mm) | Accepted |
|---|---|---|---|---|---|
| rear-axle | rear-axle/cyl/227 | cylinder | 8.019 | 14.644 | false |
| front-flange | front-flange/cyl/100 | cylinder | 8.019 | 13.794 | false |
| engine-bay | engine-bay/cyl/189 | cylinder | 6.378 | 11.597 | false |
| front-flange | front-flange/cyl/091 | cylinder | 5.690 | 11.245 | false |
| front-flange | front-flange/cyl/207 | cylinder | 5.657 | 10.209 | false |
| rear-axle | rear-axle/cyl/226 | cylinder | 5.646 | 9.303 | false |
| rear-flange | rear-flange/cyl/023 | cylinder | 5.545 | 9.154 | false |
| duct-route | duct-route/cyl/132 | cylinder | 5.323 | 9.125 | false |
| front-flange | front-flange/cyl/193 | cylinder | 5.149 | 8.158 | false |
| duct-route | duct-route/cyl/076 | cylinder | 4.759 | 9.780 | false |

All ten worst residuals are rejected cylinders; no accepted row (cylinder or plane) appears in this
list.

## The ~13 mm tube family

Widening the accept threshold to 1.0 mm was aimed at a cluster of well-supported ~13 mm-radius
cylinders that were rejected under the original 0.8 mm cutoff. Checking every cylinder with radius
12.5–15.5 mm and support over 50,000 points (81 candidates across five regions): 48 are now
accepted, 33 remain rejected, several with rms well over 1.0 mm (up to 2.29 mm). This is not one
tube gauge landing just past a threshold — it is a mix of genuinely clean fits and messier ones,
likely where the same tube family crosses welds or other features. The cleanest example is
`tank-mounts/cyl/001` (r 13.50 mm, rms 0.223 mm, support 181,694) — the candidate to calliper first
if confirming this tube gauge.

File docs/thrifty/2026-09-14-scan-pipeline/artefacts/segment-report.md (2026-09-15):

# Segment report — CloudCompare RANSAC per region

CloudCompare command as plan section 4.5, run once per region's `<region>_pts.ply` (full-res
crop points), full-res, not the 5 M-decimation reference cloud of section 5.5.

| Region | Primitives | Cylinders | Planes | Points assigned | 11–16 mm bracket | 17–20 mm bracket | 22–26 mm bracket |
|---|---|---|---|---|---|---|---|
| engine-bay | 347 | 193 | 154 | 70.3% | 71 (rms 0.65) | 9 (rms 0.58) | 0 |
| rear-axle | 477 | 314 | 163 | 61.5% | 42 (rms 0.56) | 13 (rms 0.59) | 10 (rms 0.58) |
| rear-flange | 150 | 92 | 58 | 70.7% | 31 (rms 0.51) | 4 (rms 0.69) | 1 (rms 0.55) |
| front-flange | 362 | 246 | 116 | 57.6% | 42 (rms 0.62) | 7 (rms 0.63) | 8 (rms 0.55) |
| tank-mounts | 208 | 138 | 70 | 73.4% | 57 (rms 0.62) | 2 (rms 0.51) | 3 (rms 0.35) |
| duct-route | 265 | 159 | 106 | 71.5% | 65 (rms 0.60) | 8 (rms 0.51) | 7 (rms 0.59) |

The fraction of points assigned runs 58–73% across regions, well above the 42.8% reference in
plan section 5.5. That reference was measured on the 5 M-decimation-derived engine-bay cloud;
this WP runs RANSAC on the full-res crop points per section 4.4, which are denser and evidently
segment more completely under the same parameters.

## engine-bay — top ten primitives by support

| Kind | Index | Support | Radius (mm) | RMS (mm) |
|---|---|---|---|---|
| cylinder | 3 | 29137 | 12.70 | 0.852 |
| cylinder | 1 | 28912 | 13.13 | 0.822 |
| cylinder | 9 | 25830 | 13.16 | 0.840 |
| cylinder | 11 | 25646 | 14.69 | 0.468 |
| cylinder | 12 | 24492 | 13.91 | 0.915 |
| cylinder | 4 | 24076 | 13.31 | 0.767 |
| cylinder | 10 | 24002 | 86.96 | 0.665 |
| cylinder | 2 | 23943 | 12.72 | 0.739 |
| cylinder | 6 | 23461 | 14.73 | 0.829 |
| cylinder | 13 | 23448 | 14.44 | 0.823 |

## rear-axle — top ten primitives by support

| Kind | Index | Support | Radius (mm) | RMS (mm) |
|---|---|---|---|---|
| cylinder | 3 | 24117 | 27.03 | 0.869 |
| cylinder | 1 | 21407 | 24.97 | 0.547 |
| cylinder | 2 | 19172 | 70.71 | 33.104 |
| plane | 1 | 14464 | — | 0.329 |
| cylinder | 6 | 14277 | 87.44 | 45.236 |
| cylinder | 4 | 13609 | 136.77 | 77.597 |
| cylinder | 7 | 10793 | 119.12 | 37.814 |
| cylinder | 5 | 9947 | 19.08 | 0.624 |
| cylinder | 31 | 9932 | 87.86 | 35.436 |
| cylinder | 14 | 9781 | 25.90 | 0.588 |

The two highest-support cylinders (index 3, r 27.03 mm; index 1, r 24.97 mm) are the rear axle
housings — radius in range 22–30 mm as the plan's section 5.4 reference (r 24.6 / 23.9 mm), rms
under 0.87 mm. A further four cylinders in the 20–30 mm bracket with axis within 8° of Y also
appear (support 1489–4156, a tenth or less of the two housings' support) — smaller-radius,
lower-support finds in the same bracket rather than a second pair of housings; RANSAC parameters
are unchanged from section 4.5 per the scope fence, so this is reported as observed rather than
filtered by support.

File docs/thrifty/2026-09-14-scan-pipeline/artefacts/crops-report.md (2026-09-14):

# Crop stage — six regions

Boxes and fractions per `pipeline/crops.toml` and plan section 4.4. Fraction is the share of
above-floor (Z > 6 mm) vertices of `chassis_datum_5M.stl` inside each box; expected values were
measured on the owner's workstation on 2026-09-14.

| Region | Box (x / y / z, mm) | Points | Fraction | Expected | Diff (pp) |
|---|---|---|---|---|---|
| engine-bay | [400,1100] / [-350,350] / [80,800] | 1 451 797 | 0.1204 | 0.1204 | -0.005 |
| tank-mounts | [300,1200] / [-250,250] / [620,1000] | 987 377 | 0.0819 | 0.0819 | -0.005 |
| front-flange | [950,1350] / [-200,200] / [200,650] | 1 260 019 | 0.1045 | 0.1047 | -0.025 |
| rear-flange | [300,650] / [-250,250] / [150,550] | 535 154 | 0.0444 | 0.0442 | 0.016 |
| duct-route | [450,1150] / [-180,180] / [150,800] | 1 170 330 | 0.0970 | 0.0971 | -0.008 |
| rear-axle | [-150,150] / [-480,480] / [150,480] | 1 340 702 | 0.1111 | 0.1112 | -0.006 |

All six fractions are within 0.03 percentage points of expected, well inside the 1.5 pp tolerance.

Renders (plan view left, side view right, 0.6 mm per pixel):

- [crop-engine-bay.png](crop-engine-bay.png)
- [crop-tank-mounts.png](crop-tank-mounts.png)
- [crop-front-flange.png](crop-front-flange.png)
- [crop-rear-flange.png](crop-rear-flange.png)
- [crop-duct-route.png](crop-duct-route.png)
- [crop-rear-axle.png](crop-rear-axle.png)

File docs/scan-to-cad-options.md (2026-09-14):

# Scan-to-CAD base: options and ranking

14 September 2026

## Answer

AI can carry the heavy lifting on this modelling job, but not the part the market
advertises. Nothing shipping in September 2026 rebuilds a vehicle chassis from a scan.
What AI does reliably today is three things: run a scripted mesh-conditioning pipeline,
fit geometric primitives to cropped regions of the scan with a human check, and write and
execute the parametric CAD that produces STEP, drawings and flat patterns. That is enough
here, because the design only needs the interfaces reverse-engineered and the rest of the
scan stays as a reference mesh. Conversion shops work the same way: Fellten, Jaunt,
Electrogenic and EV West all keep the scan as a fit-check backdrop and model only the
mating features.

The scan is better than the README assumed. It is the stripped rolling chassis: bare
frame, both differentials, suspension, wheels and steering, with the engine bay empty and
the engine-mount plates and their bolt holes resolved even in the low-res export. The fuel
tank, seat, bodywork and CVT ducting are not in it.

### Ranking

The options compose rather than compete. Option 1 is the foundation for everything else,
2 is the default for interface capture and design, 3 is a cheap parallel ask, and 4 and 5
are escalations.

| # | Option | Cost | Evidence |
| --- | --- | --- | --- |
| 1 | **Scripted conditioning pipeline.** PyMeshLab, Open3D and trimesh in a Python venv, CloudCompare's RANSAC shape detection for multi-primitive segmentation, all written and run by Claude Code. | Nil | Run on this file today. Full-res cleaned and decimated in 12 min; a round tube fitted at 0.40 mm RMS. |
| 2 | **Fusion 360 as the reference workspace.** Cropped meshes as backdrop; Mesh Section Sketch and Fit Curves for tube runs; Autodesk Assistant and the Fusion MCP for scripted features, sheet metal and DXF flat patterns. | Commercial Fusion A$985/yr; A$739 first year under a promotion ending 21 Sep 2026 | Documented. Autodesk caps mesh-to-solid conversion at 10,000 elements and says Prismatic conversion is not for scan data, so the scan is never converted, only referenced. |
| 3 | **Re-exports from the scanning provider's Artec project.** Cleaned floor-free mesh, OBJ or PLY with colour, fitted planes and cylinders as STEP, section sets on named planes. | A request | Artec Studio 20 fits constrained primitives and exports STEP, IGES and X_T. Whether the provider still holds the project is unknown. |
| 4 | **Backflip AI on cropped bosses and brackets.** | 60 free credits, then US$20/month | The only shipping mesh-to-feature-tree product. One independent test on small parts lost fine detail; no published result on a tube frame; vendor scope is 3-axis milled and turned parts. |
| 5 | **Dedicated reverse-engineering software.** QuickSurface Pro, or Geomagic Design X. | QuickSurface Pro A$2,900/yr with a 30-day trial; Design X Go US$1,900/yr, and the Pipe Wizard is Pro at US$7,280/yr | The proper route. QuickSurface's bicycle-frame case study finished a whole frame in under 1.5 h. Escalate only if the tube runs stall in options 1 and 2. |

Excluded with reasons:

- Text- and image-to-3D generators (Meshy, Tripo, Hunyuan3D, TRELLIS) emit meshes with no
  B-rep, no dimensions and no relation to the scan.
- Research point-cloud-to-CAD models (CAD-Recode, cadrille, HoLa, Point2CAD) are trained
  on single small parts; only HoLa reports results on real scans and it has no public
  weights. CAD-Recode is licensed non-commercial.
- Zoo Design Studio imports meshes as read-only reference and has no mesh-to-KCL path.
- Blender has no B-rep, STEP, sheet-metal or drawing output.

## What the scan contains

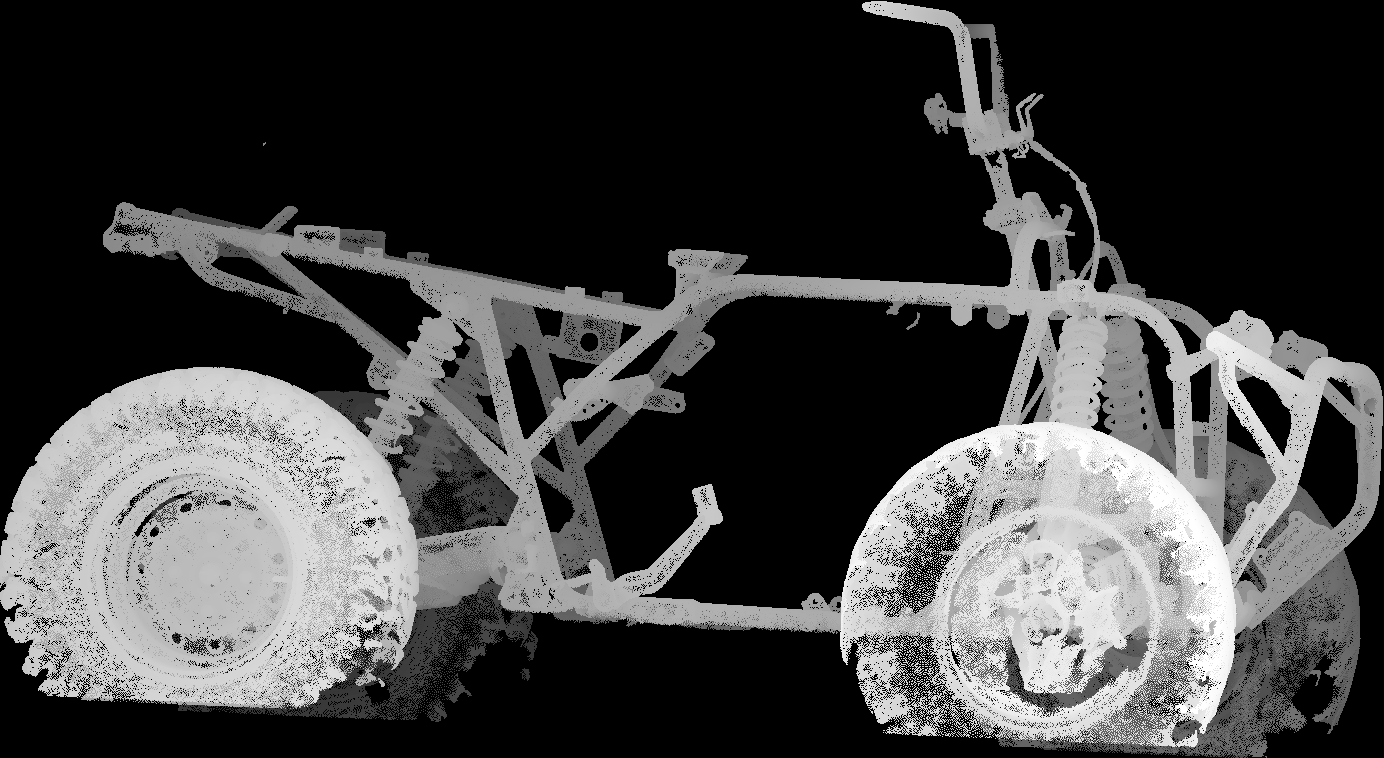
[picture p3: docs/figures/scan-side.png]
Side view of the low-res scan: bare frame, wheels, suspension and handlebars


Present: frame, both differentials, front propeller-shaft stub at the front differential,
swingarm and rear axle housing, A-arms, shocks, wheels and tyres, steering and handlebars,
front bumper. Absent: engine, CVT and its moulded ducting, fuel tank, seat, racks'
plastics, bodywork.

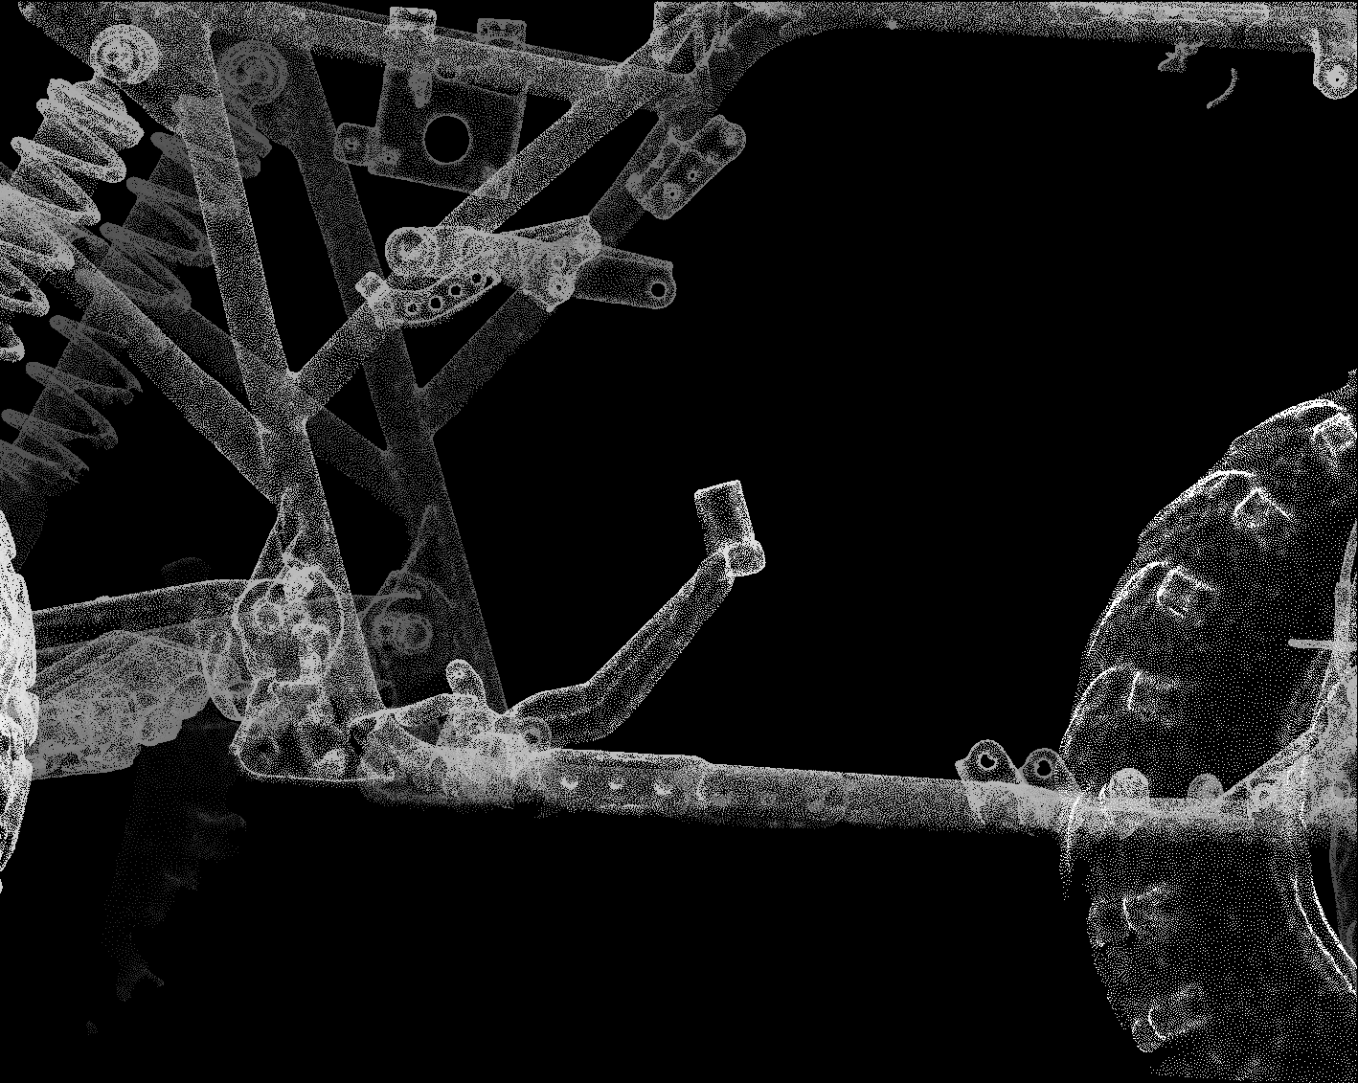
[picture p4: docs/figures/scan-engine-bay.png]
Engine bay from the side: empty cradle with mount plates and bolt holes


| Measured | Low-res | Full-res |
| --- | --- | --- |
| Faces | 1 844 914 | 35 074 344 |
| Unique vertices | 949 257 | 17 640 311 |
| Connected pieces | 126; the largest holds 77% of faces | Fragments under 0.01% of faces total 0.13% |
| Surface area | 5.51 m² | 8.26 m² |
| Floor | Absent; largest plane holds 1.3% of vertices | Present; 13.9% of vertices in the 1 M decimation |
| Boundary edges | 58 630 | Not measured |
| Non-manifold edges | 0 | Not measured |
| Degenerate faces | 0 | Not measured |

The 2.7 m² difference is the floor. The full-res export carries a large irregular patch of
ground under and around the machine; the low-res export had it removed.

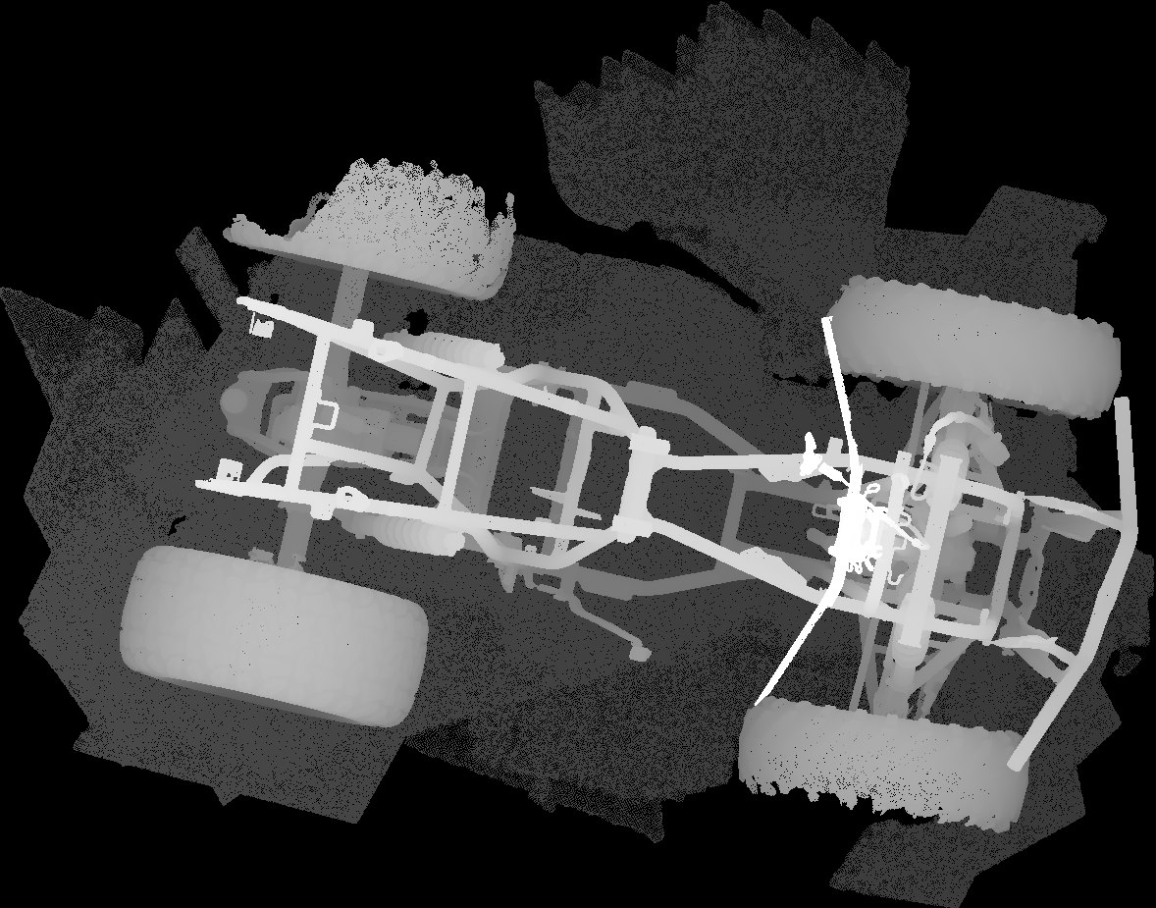
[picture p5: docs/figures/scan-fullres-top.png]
Top view of the full-res scan showing the floor patch around the chassis


Orientation: Z is up. The mesh is yawed about 29° in its own frame and the floor normal is
2.7° off the scan's Z axis. Principal-component alignment is not a usable datum because
the wheels and racks skew it. The vehicle datum has to come from the floor plane for Z,
the frame's symmetry plane for Y and an axle or flange face for the X origin. The floor
plane fits with 1.18 mm RMS on the 1 M mesh, which is good enough for Z.

### Frame members

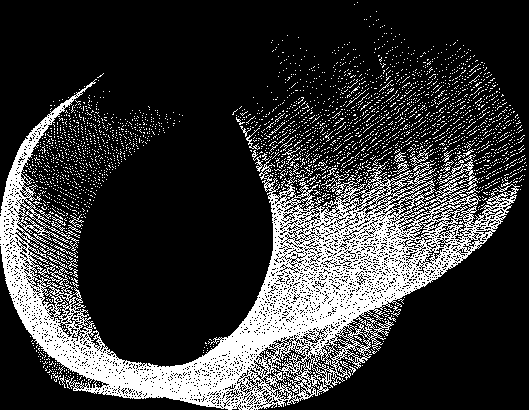
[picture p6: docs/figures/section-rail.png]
End-on section of a slanted lower rail: a round tube with a plate welded beside it

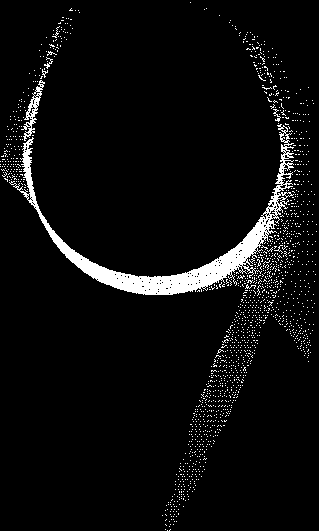
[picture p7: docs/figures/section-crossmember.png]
End-on section of a cross-member: a round tube with a tab


The frame is round tube of at least two sizes with plates and tabs welded alongside.
Circle fits give outside diameters of 25.9 mm and 36.9 mm; callipers should confirm both.

| Member and mesh | Radius | Inliers | RMS | 95th percentile |
| --- | --- | --- | --- | --- |
| Cross-member, low-res | 13.47 mm | 89.7% | 0.88 mm | not recorded |
| Cross-member, full-res | 12.94 mm | 92.6% | 0.40 mm | 0.80 mm |
| Lower rail, full-res, box crop | 18.43 mm | 98.2% | 4.04 mm | 8.79 mm |

The cross-member fit shows what the scan can do: a tube resolved to well under half a
millimetre at full resolution, and twice as well as the low-res export. The rail fit
shows what a naive approach cannot do: a box crop takes in the welded plate and the
circle fit degrades to 4 mm RMS. Members have to be segmented into planes and cylinders
before fitting. That is what CloudCompare's RANSAC shape detection, QuickSurface's
primitive extraction and Design X's regions all do, and it is why option 1 names
CloudCompare rather than relying on a single-model fit.

### Consequences

- Full-res crops for interface fitting; the 1 M or 200 k decimations for the CAD backdrop.
- The tank envelope, seat base and plastics need a second scan or physical measurement
  before the controller box is drawn.
- The README states that the CVT ducts and fan bracket are in the scan. The renders do
  not show them; the engine bay is bare.

## Evidence from this machine

Workstation: i7-12700KF, 20 threads, 31.8 GB RAM, GTX 1060 3 GB. The full-res file is
local on the project drive and reads sequentially at about 626 MB/s.

| Operation | Tool | Time | Memory |
| --- | --- | --- | --- |
| Parse low-res binary STL | numpy | 0.2 s | small |
| Unique vertices, low-res | numpy | 2.7 s | small |
| Connected components, low-res | scipy | 0.2 s | small |
| Stream full-res in 4 M-face chunks and crop | numpy | 200 s | under 1 GB |
| Load full-res | PyMeshLab | 154 s | 10.7 GB |
| Remove fragments, duplicates, null faces | PyMeshLab | 20 s | 11.9 GB |
| Save cleaned PLY, 878 MB | PyMeshLab | 5 s | 11.9 GB |
| Decimate 35 M to 5 M faces | PyMeshLab | 435 s | about 18 GB peak |
| Decimate 5 M to 1 M faces | PyMeshLab | 59 s | 6.6 GB |
| Load low-res | PyMeshLab | 7.9 s | 0.6 GB |
| Decimate 1.8 M to 500 k, then 150 k | PyMeshLab | 18.7 s, 4.7 s | 0.8 GB |
| Read, cluster, decimate to 500 k, low-res | Open3D | 2.5 s, 2.2 s, 19.0 s | 0.5 GB |
| Load, split, section, low-res | trimesh | 2.4 s, 3.3 s, 0.2 s | small |
| Floor plane RANSAC on the 1 M mesh | Open3D | 0.3 s | small |
| Single-cylinder RANSAC, 750 points | pyransac3d | 1.2 s | small |

What these runs establish, and what failure would have looked like:

- The full-res file is tractable on this PC with free tools. Failure would have been an
  out-of-memory kill or an hours-long run; the peak was 18 GB of the 32 GB available.
- The full-res mesh resolves a tube to 0.40 mm RMS. Failure would have been several
  millimetres, as the contaminated rail crop produced.
- Box cropping is not a segmentation. The rail fits failed exactly as expected, which is
  why the pipeline needs multi-primitive detection before fitting.
- numpy's `np.fromfile` returned zero records on the 1.75 GB file; chunked `readinto`
  streams it without issue.
- pyransac3d agreed with the normals-based fit on the cross-member radius but kept only
  20% of points as inliers, and its own documentation says its cylinder model does not
  perform well on real data. It is fine for planes, not for the rails.

Not established today: any run inside Fusion, because Fusion was not yet installed; a
symmetry-plane fit; a full multi-primitive segmentation of the engine bay.

## The AI landscape for manufacturable output

### Scan in, CAD out

- **Backflip AI** is the one shipping product that turns a mesh into an editable feature
  tree, as a Fusion add-in with a native timeline or as STEP from the web app. Input is
  STL, OBJ, PLY, GLB or GLTF; no triangle limit, tolerance or API is published. The single
  independent test (engineering.com, August 2026) found that fine notches and thin walls
  were frequently lost, while a simple adaptor ring came out near-flawless in the slower
  mode. The vendor's own scope is moderate-complexity 3-axis milled and turned parts. Its
  place here is an experiment on one cropped mount bracket, not a plan.
- **Fusion's Convert Mesh** is not a route. Autodesk's support articles set a ceiling of
  10,000 elements for successful conversion and state that the Prismatic method is meant
  for meshes exported from other CAD software, not scan data. Personal-use licences do not
  include Prismatic at all.
- **Research models** that take a point cloud and emit CAD (CAD-Recode, cadrille,
  CADReasoner, HoLa, ParaCAD, Point2CAD) are trained on DeepCAD, ABC and Fusion 360
  Gallery parts normalised to a unit cube. None has been demonstrated on anything like a
  chassis. cadrille is Apache-licensed with public weights and is the only candidate for
  a weekend experiment on a cropped point cloud.
- **Dedicated reverse-engineering software** is not AI but is where the automation is:
  QuickSurface extracts constrained planes, cylinders, cones and spheres, aligns the mesh
  to world coordinates from them and exports STEP; Geomagic Design X Pro adds automatic
  regions and a Pipe Wizard that returns a centreline from a tube region. Hexagon has owned
  Geomagic since April 2025.

### Text or code in, CAD out

- **Autodesk Fusion.** Autodesk Assistant left tech preview and is generally available in
  the 3 September 2026 release; it runs sketches, extrudes, fillets, holes, patterns and
  parameter edits, and since April 2026 can write and execute Fusion API scripts. The
  official local Fusion MCP is listed as generally available and works with Claude
  Desktop or any MCP client against a running Fusion session. Autodesk's own sample server
  exposes one tool that executes API scripts and one that takes screenshots, and its
  guidance says building components from sketches is often out of scope. Community
  servers add an `execute_python` tool and, in one case, sheet-metal flange, bend and
  flat-pattern tools. One second-hand report quotes Autodesk support saying third-party
  AI tools cannot be integrated on a personal-use licence.
- **Fusion API.** Sheet-metal features, unfold and flat pattern are scriptable, and the
  DXF flat-pattern export writes outer and inner profiles, bend centre lines and extent
  lines on separate layers with a K-factor from the rule table. This is the most mature
  scripted flat-pattern route available. Drawings can be created automatically through
  the API but dimensions are still placed by hand.
- **Code-CAD.** build123d and CadQuery produce STEP B-rep from Python and run headless
  inside Claude Code on Windows on the `cadquery-ocp` 7.9 wheels. Neither has sheet-metal
  unfold; build123d's request for it has been open since 2023. Dimensioned PDF drawings
  from script exist in exactly one place, draftwright, which is alpha. FreeCAD's
  SheetMetal workbench unfolds with K-factor tables and writes bend lines to DXF, and its
  Python entry points are GUI-free by inspection of the source.
- **How well language models write this code.** Text2CAD-Bench (May 2026) puts the best
  model at 11% invalid output on basic parts and 68% invalid on parts with fillets,
  sweeps and lofts. BenchCAD found 64% of nominally successful edits silently corrupt
  unrelated features. The chain-drive housing lives in exactly that territory, so
  verification (measure, interference-check, render) is part of the loop, not an option.
- **Onshape** shipped a FeatureScript MCP server through Onshape Labs in August 2026; the
  agent writes and debugs a real parametric feature. It needs a paid seat and a platform
  switch, and no outsider has evaluated it.
- **Zoo** exports STEP from KCL through a CLI and an MCP server but has no sheet metal or
  drawings until 2027 and treats meshes as reference only.

### How conversion shops do it

Fellten imports scan data into Fusion to check fit before prototyping. Jaunt Motors
scanned a Land Rover chassis and engine bay with an Artec Leo, overlaid batteries on the
mesh, refined in Fusion and handed the fabricator PDF drawings and DXF for the laser.
Electrogenic scans the gearbox housing and engine bay; EV West scans the transmission and
flywheel to design adapter plates. None describes remodelling a frame. No quad or ATV
conversion build log that used a scan was found.

## Proposed pipeline

The stages match the README's workflow table. Options 3 to 5 slot into interface capture
if needed; they do not change the shape of the pipeline.

| Stage | Tools | AI does | Human does | Output |
| --- | --- | --- | --- | --- |
| Condition | PyMeshLab, Open3D | Remove fragments; fit the floor plane and cut everything below it; fit the symmetry plane; set X from an axle or flange; apply the transform; export 5 M, 1 M and 200 k variants in millimetres | Check the datum against tape measurements of track, wheelbase and rail spacing | Cleaned, aligned PLY and STL; the transform recorded as a matrix |
| Crop | trimesh, PyMeshLab | Cut named regions: engine bay, tank mounts, front and rear flanges, duct route | Name the regions | One full-res mesh per region |
| Segment and fit | CloudCompare RANSAC, numpy | Sample each crop to points; detect planes and cylinders with radius bracketed to calliper OD ± 0.5 mm; tabulate axes, radii and plane normals; skeletonise bends if needed | Reject false primitives; supply calliper values | Primitive table with residuals |
| Interface capture | build123d, or the Fusion API | Build sweeps along fitted axes, mount planes, boss cylinders and bolt patterns at calliper spacing; export STEP; report cloud-to-mesh deviation | Confirm bolt sizes, threads, bush bores and flange data from the parts | Interface STEP with a deviation map |
| Design | build123d for the drive housing and brackets; Fusion sheet metal for boxes, ducts and the finned base | Generate parametric parts from the parameter table; interference and clearance assertions; multi-view renders | Design judgement; ratio and packaging decisions | STEP assemblies |
| Handover | Fusion drawings and flat patterns; draftwright for plate and shaft drawings | Auto-create drawings and DXF R14 flat patterns with bend lines; cut list | Place and check dimensions, welds, tolerances and adjustment ranges | STEP, PDF, DXF, cut list, reference STL |

## Interfaces to measure by hand

- Tube outside diameter and wall. Fusion smoothing and decimation bias fitted radii, and
  the RANSAC radius bracket needs the true value.
- Engine-mount hole diameters, threads, bush bores and hole spacings. Small metallic holes
  are where structured light fails; the scan gives the mount plane and the boss axis, not
  the bore.
- Propeller-shaft flange PCD, pilot diameter, bolt size, spline data and yoke plunge. The
  scan gives axis and face position only.
- Chain line and sprocket coplanarity. The 0.1 to 0.2 mm per 100 mm the chain wants is
  below whole-vehicle scan accuracy; build it adjustable and set it on assembly.
- Suspension position at scan time. Propeller-shaft operating angles must be confirmed
  at ride height under the final mass, because the scan may have been taken with the
  suspension at droop.

Universal-joint guidance: operating angles between 0.5° and 3°, and the two ends equal
within 1°, or within 0.5° for shafts ahead of a transfer position. A 1 mm positional
error over a 300 mm shaft is about 0.2°, so shaft angles from the scan are usable
against that rule.

## Decisions

1. **Fusion licence.** The commercial subscription is the one that carries Prismatic
   conversion and, by one report, AI tool integration, and the personal-use terms exclude
   commercial work. The 25% first-year promotion ends 21 September 2026.
2. **Ask the scanning provider** for re-exports from the Artec project: the cleaned mesh
   without the floor, OBJ or PLY with colour, the fusion resolution and any shape-deviation
   decimation used, whether hole filling was applied, and STEP of any planes or cylinders
   they can fit to the engine-bay rails and mount plates.
3. **Second scan or measurement** of the fuel tank, seat base and side plastics, and the
   CVT ducts if the duct route is to be reused.
4. **Whether to trial QuickSurface** now, in parallel with option 1, or hold it as the
   escalation.
5. **README correction** on the ducts and fan bracket.

## Not verified

- The exact tool list of the official Fusion MCP, and whether it exports STEP or DXF
  itself.
- Autodesk's own article on personal-use licences and AI tools; the claim is second-hand.
- Backflip's input size limits and any tolerance figure.
- Whether the scanning provider still holds the Artec project or will re-export.
- Geomagic Design X pricing from Hexagon directly; whether the Pipe Wizard sits in the Pro
  tier only. Reseller price books say it does.
- QuickSurface's claim of handling 100 million triangles, and whether it can be scripted.
- Any published behaviour of Fusion with a 1 M-face reference mesh; the 10,000-element
  figure is for conversion, not display.
- The FreeCAD SheetMetal headless unfold; read from source, not run.
- Whether the King Quad LT-A400F engine mounts are rubber-bushed.
- The dedicated library-documentation research stream did not complete; the pipeline stack
  rests on the runs above and on the scan-to-CAD stream's coverage of the open-source
  tools.

## Sources

- Autodesk, Converting 3D scan mesh to Prismatic solid in Fusion, 27 Jan 2026: https://www.autodesk.com/support/technical/article/caas/sfdcarticles/sfdcarticles/Converting-3D-scan-mesh-to-Prismatic-solid-in-Fusion-360.html
- Autodesk, Slow performance after inserting or converting a mesh, 15 Jul 2026: https://www.autodesk.com/support/technical/article/caas/sfdcarticles/sfdcarticles/Fusion-360-performance-slows-after-inserting-mesh.html
- Autodesk, The Prismatic option is missing on a personal-use licence, 13 Aug 2026: https://www.autodesk.com/support/technical/article/caas/sfdcarticles/sfdcarticles/The-prismatic-option-is-missing-in-the-convert-mesh-menu-in-Fusion-360.html
- Autodesk, Fusion September 2026 update: https://www.autodesk.com/products/fusion-360/blog/september-2026-major-product-update-whats-new/
- Autodesk, Introducing the Fusion MCP, 7 May 2026: https://www.autodesk.com/products/fusion-360/blog/introducing-the-fusion-mcp-opening-fusion-to-ai-powered-workflows/
- Autodesk, FusionMCPSample: https://github.com/AutodeskFusion360/FusionMCPSample
- Autodesk, Fusion mesh section sketch: https://help.autodesk.com/cloudhelp/ENU/Fusion-Mesh/files/MESH-CREATE-MESH-SECTION-SKETCH.htm
- Autodesk Australia, Fusion extensions and pricing: https://www.autodesk.com/au/products/fusion-360/extensions
- Autodesk, Backflip add-in for Fusion, 19 Aug 2026: https://www.autodesk.com/products/fusion-360/blog/backflip-add-in-autodesk-fusion/
- engineering.com, Backflip's back: is the mesh-to-CAD AI real this time?, 4 Aug 2026: https://www.engineering.com/backflips-back-is-the-mesh-to-cad-ai-real-this-time/
- Backflip pricing: https://www.backflip.ai/pricing
- Hexagon, Geomagic Design X plans: https://hexagon.com/products/geomagic-design-x/geomagic-design-x-plans
- Rev1 Tech, Geomagic Design X price book: https://rev1tech.com/shop/software/reverse-engineering/geomagic-design-x
- QuickSurface pricing: https://www.quicksurface.com/price/
- Smart Technology, QuickSurface Australian pricing: https://smarttechnology.com.au/quicksurface-3d-surface-to-cad-software/
- QuickSurface, bike frame case study, 16 Dec 2025: https://www.quicksurface.com/case-study-reverse-engineering-a-bike-frame-with-quicksurface/
- Artec Studio 20, CAD primitives: https://docs.artec3d.com/as/20/en/cad.html
- CloudCompare, RANSAC shape detection command-line keywords: https://raw.githubusercontent.com/CloudCompare/CloudCompare/master/plugins/core/Standard/qRANSAC_SD/include/qRANSAC_SD_Commands.h
- pyransac3d cylinder documentation: https://leomariga.github.io/pyRANSAC-3D/api-documentation/cylinder/
- Text2CAD-Bench, May 2026: https://arxiv.org/html/2605.18430
- BenchCAD, May 2026: https://arxiv.org/html/2605.10865v1
- cadrille: https://github.com/col14m/cadrille
- Onshape, FeatureScript MCP server, 11 Aug 2026: https://www.onshape.com/en/blog/featurescript-mcp-server-enables-text-code-cad
- Zoo roadmap: https://zoo.dev/roadmap
- build123d sheet-metal issue: https://github.com/gumyr/build123d/issues/305
- draftwright: https://github.com/pzfreo/draftwright
- FreeCAD SheetMetal workbench: https://github.com/shaise/FreeCAD_SheetMetal
- DEVELOP3D, Fellten, 1 Dec 2025: https://develop3d.com/sponsored/fellten-bringing-classic-cars-into-the-electric-era/
- Shapr3D, Jaunt Motors case study, 1 Aug 2022: https://www.shapr3d.com/content-library/building-a-movement-for-electric-vehicles
- Spicer, driveline operating angle: https://spicerparts.com/calculators/driveline-operating-angle-calculator
- Wippermann, chain drive alignment: https://wippermann.com/en/service/maintenance/alignment-chain-drives
- Fused Fabrications, preparing your file: https://fusedfabrications.com.au/preparing-your-file/

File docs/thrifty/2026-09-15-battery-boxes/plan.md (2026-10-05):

# Battery boxes: cell, block, enclosure, placement, clearance — Plan

| Property | Value |
|---|---|
| Date | 2026-09-15 |
| Owner | Jeremy |
| Repo | electric-butterfly/equad |
| Tier | 2 Sub-project |
| Status | Draft |

---

## 1. Purpose

The eQuad carries its 26S2P pack as two enclosures of 26 CALB L148N58A cells, one each side of
the frame, leaning together over the propeller-shaft channel in an inverted V. Whether that volume
exists on this frame has been an open question since the fabricator first doubted it. The scan
pipeline (`docs/thrifty/2026-09-14-scan-pipeline/`) has now put the chassis on a vehicle datum with
its tube runs and mount plates fitted, so the question can be answered by geometry rather than
argument: build the cell, pattern the block, wrap it in the enclosure, place two of them on the
datum, and measure the clearance to the frame across the whole family of lean angles and offsets.

This plan delivers the parametric CAD for the battery boxes in `cad/` and the placement study
against the scanned frame. Everything is driven from one parameter file, `cad/params.toml`
(section 4.2), so that when the owner measures the inter-cell pad, tape-measures the motor, or
Sam scans the plastics, the whole chain re-runs from the new numbers with no redesign. The output
for the fabricator is STEP, with every body named and coloured so that Fusion and SolidWorks list
the parts by name; the output for the owner is a self-contained HTML viewer, a handover document,
and a Fusion import check that proves the datum origin and axes arrive where the CAD put them.

**How to use this document.** Each work package is standalone. Open a new session, set the model and
effort the WP names, paste its starter prompt verbatim. The prompt points back here for the schema
and the rules. **One work package per session.** Never two.

**If a work package pauses** — it hit its item cap, ran short of context, or you stopped it — paste
the *same* starter prompt into a fresh session. It finds the WP's branch, reads how far the last
session got, and carries on. There is nothing to reconstruct and nothing to decide.

---

## 2. Scope

| | |
|---|---|
| **In scope** | Seven scripts under `cad/` driven by `cad/params.toml`: cell and block, enclosure, vehicle assembly, clearance sweep, mount pickups, viewer and handover, and the Fusion import pack. STEP for one cell, the 26-cell block, one enclosure with and without cells, and the two-box vehicle assembly with a motor placeholder, every body named and coloured (section 4.10), plus a datum marker STEP and a Fusion import workflow document (section 4.11). A clearance sweep of the box against the datum-aligned frame mesh over lean, lateral offset, height and X station, with section renders. A table of frame primitives within reach of the chosen placement, as mount pickups. One HTML viewer and one HTML handover document for the fabricator. |
| **Out of scope** | Busbars, BMS leads, insulating covers and their routing — represented only by the headroom parameter. Bracket design — Sam's, from the pickup table. The central contactor and paralleling box, the switchgear box, the controller box, the intermediate drive. Plastics, foot boards, tank and seat base: not in the scan, so not in the sweep (section 9, owner action 5). Modelling inside Fusion: this plan delivers files that import into Fusion and a procedure to prove they landed correctly, and builds nothing in Fusion. Any edit under `pipeline/` or `docs/thrifty/2026-09-14-scan-pipeline/`. |
| **The frame is the only obstacle in this plan** | The scan is the stripped rolling chassis. The sweep measures clearance to the frame, the placeholder motor and the propeller-shaft keep-out. It says nothing about the plastics, and the report must say so in its first line. When the plastics are scanned, the same sweep re-runs with a second obstacle mesh. |
| **The chamfer is off by default** | The front column holds eight cells; the empty ninth position is the fuse bay. A chamfer on the front top edge is a parameter (`chamfer_front_top`) defaulting to 0. WP-04 reports whether a non-zero value would buy clearance. It is fabricated only if it does. |
| **Placement is a parameter set, not a decision** | Section 4.6 defines the box-local frame and the transform. The defaults in `[placement]` are a feasible point from today's sweep (section 5.5). The owner replaces them after WP-04 and before WP-05 (section 9). |
| **build123d, not Fusion** | STEP is what Sam's SolidWorks and Fusion both read. build123d 0.11.1 in `.venv-cad` builds, exports and re-imports every solid in this plan in under a second each (section 5.2), and FreeCAD 1.1.3 re-imports the STEP with identical solid count and volume (section 5.3). That re-import is the lossless read path every WP verifies against. build123d remains the master; Fusion is where Sam designs brackets against the imported geometry, and a placement change is made in `params.toml` and regenerated, never edited in Fusion. |
| **Derived data is local and git-ignored** | Meshes and STEP files over 1.5 MB live under `data/cad/`, regenerable from `params.toml`. Committed artefacts are small: STEP under 1.5 MB, JSON, Markdown, PNG renders, and the HTML files, the viewer capped at 8 MB. |

---

## 3. Target state

When this plan is finished:

- `cad/params.toml` holds every dimension the boxes depend on, each with its source, and every
  script reads it and nothing else.
- `cad/cell.py` builds the cell and the 26-cell block; `cad/enclosure.py` builds the enclosure with
  its lid, end plates, compression plate, fuse bay and cable exits; both export STEP that FreeCAD
  re-imports with the same solid count and volume.
- `cad/assembly.py` places two enclosures on the ISO 8855 datum by the `[placement]` parameters,
  mirrored about the symmetry plane, with the motor placeholder and the propeller-shaft keep-out,
  and writes `placement.json` with the eight corners of each box in vehicle coordinates.
- `cad/clearance.py` evaluates any placement against the frame mesh in under a second and has
  swept the grid in section 4.7, writing `sweep.json`, a feasibility table and section renders.
- `cad/mounts.py` lists every fitted frame cylinder and RANSAC plane within reach of the chosen
  placement, with its distance to the nearest box face.
- `artefacts/viewer.html` opens in a browser with no server and shows the chassis, both boxes,
  the motor and the keep-out with per-body toggles and a section plane.
- `artefacts/sam-battery-boxes.html` is the handover: what the boxes are, the parameter table,
  the placement, the clearance result, the pickups, and the open items.
- Every STEP file carries a name and a colour on every body (section 4.10), so an importer lists
  `box_left`, `motor` and `lid` rather than `COMPOUND`.
- `artefacts/datum-marker.step` and `artefacts/fusion-import.html` let the owner import the CAD
  into Fusion and prove, in under a minute, that the origin, the axis directions and the units
  arrived unchanged (section 4.11).

**Measured baseline, 2026-09-15:**

| | count |
|---|---|
| Scripts under `cad/` | 0 |
| STEP artefacts in the repo | 0 |
| Cells per box, columns front to rear | 26 as 8 + 9 + 9 |
| Placements evaluated at X 700 (lean 0–40°, Y 200–400, Z 300–450) | 567 |
| Of those, no frame point inside the box and 10 mm clear | 216 |
| Best frame clearance found at lean 30° | 52.1 mm at Y 400, Z 450 |

---

## 4. The CAD contract — normative

### 4.1 Files and layout

```text
cad/
  README.md                 how to run each stage, which venv, in what order
  params.toml               the parameter file, section 4.2 verbatim; the only input every script reads
  common.py                 WP-01: params loading, repo root, STEP export with FreeCAD round-trip check
  cell.py                   WP-01: cell solid and 26-cell block
  enclosure.py              WP-02: enclosure, lid, internals, fuse bay, cable exits, box STEP
  assembly.py               WP-03: two boxes on the datum, motor placeholder, keep-out, placement.json
  clearance.py              WP-04: placement evaluation, sweep, section renders
  mounts.py                 WP-05: frame primitives within reach of the placed box
  viewer.py                 WP-06: builds artefacts/viewer.html
  fusion_pack.py            WP-07: datum-marker.step and fusion-import.html
data/cad/                   git-ignored (data/ is already in .gitignore)
  assembly-full.step        WP-03: the assembly with all 52 cells
docs/thrifty/2026-09-15-battery-boxes/artefacts/
  cell.step                 WP-01
  block.step                WP-01: 26 solids
  cell-report.md            WP-01
  box.step                  WP-02: enclosure, lid and internals, no cells
  box-full.step             WP-02: enclosure with the block
  box-shell.stl             WP-02: outer shell only, box-local frame, for the sweep
  enclosure-report.md       WP-02
  assembly.step             WP-03: two enclosures, motor placeholder, keep-out, no cells
  placement.json            WP-03
  sweep.json                WP-04
  sweep-report.md           WP-04
  section-yz-default.png, section-xz-default.png, section-xy-default.png    WP-04
  section-yz-best.png, section-xz-best.png, section-xy-best.png             WP-04
  mount-pickups.json        WP-05
  mounts-report.md          WP-05
  viewer.html               WP-06
  sam-battery-boxes.html    WP-06
  datum-marker.step         WP-07
  fusion-import.html        WP-07
```

Every script is run from the repo root. `cell.py`, `enclosure.py`, `assembly.py`, `viewer.py` and
`fusion_pack.py` run under `.venv-cad`; `clearance.py` and `mounts.py` run under `.venv-mesh`. Every script resolves
the repo root with `git rev-parse --show-toplevel`, loads `cad/params.toml` with the standard-library
`tomllib`, writes nothing outside `data/cad/` and
`docs/thrifty/2026-09-15-battery-boxes/artefacts/`, and refuses to run if an input it names is
missing. `common.py` reads `freecad_cmd` from `pipeline/config.local.toml` for the FreeCAD
round-trip check; no other script reads that file.

### 4.2 `cad/params.toml` — verbatim

Millimetres and degrees throughout. Every value carries its source in the comment. `OWNER` marks a
value the owner replaces from a measurement; until then the default stands and every artefact is
regenerated when it changes.

```toml
# Battery box parameters. Sources: CALB L148N58A supplier drawing (cell), owner design brief
# 2026-09-15 (block, enclosure, electrical), SIAECOSYS QSJ138D-90 outline drawing (motor),
# Littelfuse JLLN datasheet (fuse). OWNER = replace from a measurement; default stands until then.

[cell]                        # CALB L148N58A
width = 148.24                # X, terminal axis, drawing "W 148.24 +/- 0.15"
thickness = 26.66             # Y, drawing "T 26.66 +/- 0.15 at 70 % SOC, 100 +/- 10 kgf"
height = 102.8                # Z, body, drawing "102.8 +/- 0.3"
height_to_stud = 105.9        # Z, drawing "105.9 +/- 0.2"
stud_pitch = 110.6            # X between terminal centres, drawing "110.6 +/- 0.3"
stud_d = 10.88                # terminal pad diameter, drawing; thread size not on the drawing
pad = 3.0                     # OWNER: supplier-provided inter-cell pad, measure it. BOM says 3
swell = 1.0                   # per-cell growth allowance along Y at full charge; design assumption

[block]
columns = [8, 9, 9]           # cells per column, front to rear along X
column_pitch_x = 152.0        # 148.24 + 3.76 clearance between columns
fuse_slot = "inboard"         # the front column's empty ninth position sits at the inboard end
flip_odd = true               # every second cell in a column rotated 180 deg about Z so terminals alternate

[enclosure]
internal = [460.0, 300.0, 200.0]   # X, Y, Z clear inside dimensions
sheet = 3.0                   # OWNER: sheet thickness; 3 mm assumed
lid_face = "+Z"               # the terminal face; removable as a whole
lid_inset = 15.0              # bolt line inset from the outer edge
lid_bolt_d = 6.5              # M6 clearance
lid_bolt_pitch_max = 60.0     # bolts along every edge at no more than this pitch
end_plate = 6.0               # fixed reaction plate at the inboard end of the stack
partition = 3.0               # plate between the fuse bay and the front column's cells
compression_plate = 6.0       # floating plate at the outboard end of the stack
compression_wall = "outboard" # OWNER: wall the grub screws pass through; outboard assumed
compression_pairs = 5         # pairs of grub screws along X
compression_rows_z = [30.0, 75.0]   # the two rows, height above the floor
compression_screw_d = 8.0     # M8 grub screws
compression_travel_min = 10.0 # clear travel required between the plate and the wall
chamfer_front_top = 0.0       # leg length of a 45 deg chamfer on the front top outer edge; 0 = none

[electrical]
fuses_per_box = 2             # Littelfuse JLLN800 Class T, one per pole; BOM lists four
fuse_envelope = [90.0, 45.0, 60.0]   # X, Y, Z envelope of one fuse in its holder; OWNER: confirm.
                              # Datasheet 700-800 A row: A = 85.7, B = 56.4; the other columns did not parse
headroom = 60.0               # clear height above stud tops for busbars, nuts, cover and leads
cable_exit_face = "inboard"   # end wall carrying the power and sense exits
cable_exit_d = [20.0, 20.0, 25.0]   # two power glands and one sense gland, diameters
cable_exit_z = 160.0          # gland centre height above the floor

[placement]                   # left box; the right box is its mirror through Y = 0. Section 4.6
x = 743.2                     # OWNER 2026-09-17: equivalent origin-based value reproducing a hinge
                               # rotation about each box's inner-most edge - see section 4.6a
y = 39.2643                   # OWNER 2026-09-17: back-solved so the hinge edge sits at vehicle
                               # Y = +/-15 mm (30 mm gap); see section 4.6a
z = 440.4765                  # OWNER 2026-09-17: back-solved with x, y for the same hinge edge,
                               # Z = 591.57 mm; NOT verified clear of the frame (section 4.6a)
lean_deg = 82.0                # OWNER 2026-09-17: largest face (lid/floor) 8 deg off vertical
clearance_min = 10.0          # a placement passes when no frame point is inside and this is clear

[sweep]                       # WP-04 grid, applied to the left box; the right box mirrors it
x = [650.0, 700.0, 750.0]
y_range = [200.0, 400.0, 25.0]      # start, stop inclusive, step
z_range = [300.0, 450.0, 25.0]
lean_range = [0.0, 40.0, 5.0]
samples = 8000                # surface samples per placement for the distance query

[motor]                       # SIAECOSYS QSJ138D-90-4000W outline drawing, owner supplied 2026-09-15
length = 258.8                # overall along the axis, drawing "258.8 +/- 2"
housing_d = 210.0             # OWNER: tape-measure the finned housing; not dimensioned on the drawing
spigot_d = 120.0              # output-end spigot, drawing "120 -0.2"
bolt_circle_d = 131.0         # drawing "131 +/- 0.2", six M8
axis = "X"                    # OWNER 2026-09-16: in-line with the prop-shaft stack, corrected from
                               # the original cross-vehicle assumption - see section 4.6a
centre = [252.0, 0.0, 590.0]  # OWNER 2026-09-16: behind the boxes, clear of the rear shock by
                               # inspection; not scan-verified - see section 4.6a

[keepout]                     # propeller shaft plus the 150 x 100 duct, along X on the centreline
axis_y = 0.0
axis_z = 340.0                # OWNER: confirm from the front differential output height
radius = 60.0
x_range = [400.0, 1200.0]

[chassis]                     # produced by the scan pipeline, local and git-ignored
mesh = "data/derived/chassis_datum_5M.stl"      # 4 021 243 faces after floor removal
mesh_1m = "data/derived/chassis_datum_1M.stl"   # for section renders
mesh_viewer = "data/derived/chassis_datum_200k.stl"
interfaces = "docs/thrifty/2026-09-14-scan-pipeline/artefacts/interfaces.json"
primitives_engine_bay = "docs/thrifty/2026-09-14-scan-pipeline/artefacts/primitives-engine-bay.json"
```

### 4.3 The cell — `cad/cell.py`

Cell-local axes: X along the cell width (terminal axis), Y through the thickness, Z from the floor
up to the terminals. The cell origin is the centre of its bottom face.

| Element | Geometry | Check |
|---|---|---|
| Body | `Box(width, thickness, height)` with its bottom face on Z = 0 | volume = 148.24 × 26.66 × 102.8 = 406 274 mm³ |
| Studs | Two cylinders, diameter `stud_d`, height `height_to_stud − height` = 3.1, on the top face at X = ± `stud_pitch` / 2, Y = 0 | one solid after union; volume 406 850 ± 10 mm³ (measured, section 5.2) |
| Bounding box | 148.24 × 26.66 × 105.9 | exact to 0.01 |

Terminal polarity is not modelled as geometry. Cell index 0 in a column has its positive stud at
−X; `flip_odd` rotates every odd-indexed cell 180° about its own Z so terminals alternate along the
column.

### 4.4 The block — `cad/cell.py`

The block is the 26 cells in the enclosure's box-local frame (section 4.5), not their own.

| Rule | Value |
|---|---|
| Column centres along X, front to rear | −`column_pitch_x`, 0, +`column_pitch_x` |
| Cell pitch along Y | `p = thickness + pad` |
| Stack origin | the inboard end: the first cell's inboard face at `y0 = −internal[1]/2 + end_plate` |
| Cell j in a 9-cell column | centre Y = `y0 + p·j + thickness/2`, j = 0…8 |
| Front column (8 cells) | the fuse bay occupies position j = 0; cells j = 1…8 sit at the same Y as the 9-cell columns' j = 1…8; a `partition` plate sits at the outboard side of the fuse bay |
| Stack length (9 cells) | `9·p − pad` |
| Fit rule, checked by the script | `end_plate + (9·p − pad) + compression_plate + compression_travel_min ≤ internal[1]`; on failure print the four numbers and exit 2 |
| Z | every cell's bottom face on Z = 0 |
| Compound | 26 solids; bounding box X = 2·152 + 148.24 = 452.24, Y = 9·p − pad, Z = 105.9 |

With `pad = 3.0`: p = 29.66, stack = 263.94, cells span Y from −144 to 119.94, and the fit rule
leaves 24.06 mm of travel. With `pad = 1.0` the stack is 248 and the travel is 40. Both pass.

### 4.5 The enclosure — `cad/enclosure.py`

Box-local frame: origin at the centre of the floor's inside face; X forward; Y the stack axis with
+Y outboard; Z toward the lid. The internal cavity is `internal`, centred in X and Y, from Z = 0 to
Z = `internal[2]`. Every wall is `sheet` thick, outside the cavity. Folded-and-welded is a
fabrication note for Sam, not a modelling constraint: model the body as one solid.

| Element | Geometry |
|---|---|
| Body | outer box `internal + 2·sheet` in X and Y, height `internal[2] + sheet`, minus the cavity, open at +Z |
| Lid | plate `internal[0] + 2·sheet` × `internal[1] + 2·sheet` × `sheet` sitting on the wall tops; bolt holes `lid_bolt_d` on a line `lid_inset` in from the outer edge, along all four edges, at the largest pitch not exceeding `lid_bolt_pitch_max` with a hole at each corner |
| Chamfer | if `chamfer_front_top` > 0: a 45° chamfer of that leg on the outer edge where the +X wall meets the lid plane, applied to the body and the lid; else none |
| End plate | `end_plate` thick, full cavity width in X, full cavity height in Z, against the inboard wall: at the defaults Y ∈ [−150, −144] |
| Partition | `partition` thick, spanning only the front column's X range (`width` wide, centred on −152), full Z, at the outboard face of the fuse bay: at the defaults Y ∈ [−144 + p − partition, −144 + p] |
| Compression plate | `compression_plate` thick, full cavity width in X, height `height_to_stud`, floating at the outboard end of the stack: Y ∈ [y_end, y_end + compression_plate] where y_end is the outboard face of the 9-cell columns' last cell; the front column needs a spacer of `p − partition` between its last cell and the plate, modelled as a separate block |
| Grub-screw holes | `compression_pairs` × 2 holes of `compression_screw_d` through the `compression_wall`, at X stations evenly spaced across the cavity width, Z at `compression_rows_z` |
| Fuse envelopes | `fuses_per_box` boxes of `fuse_envelope`, placed in the fuse bay and the headroom above it: the first with its bottom on the floor inside the fuse bay footprint, the second on top of the first; if the second's top exceeds the cavity height, report the overrun and continue |
| Cable exits | three through-holes of `cable_exit_d` in the `cable_exit_face` wall at Z = `cable_exit_z`, spaced evenly across the middle third of the wall's X extent |
| Headroom check | `height_to_stud + headroom ≤ internal[2]`; on failure print the numbers and exit 2 |
| Interference check | the block, the end plate, the partition, the compression plate, the spacer and the fuse envelopes must have zero pairwise intersection volume with each other and with the body; report every pair with its intersection volume |

Exports: `box.step` (body, lid, end plate, partition, compression plate, spacer, fuse envelopes),
`box-full.step` (the same plus the 26 cells), and `box-shell.stl` (one closed solid the size of the
outer box, with the chamfer if any, tessellated; this is the sweep body).

### 4.6 Placement — `cad/assembly.py`

The vehicle frame is the datum frame of the scan pipeline: ISO 8855, X forward, Y left, Z up,
origin on the floor plane and the symmetry plane at the rear axle housing X.

The **left box** is placed by, for every box-local point `p`:

```text
p_vehicle = [x, y, z] + R · p_local
R = | 1    0        0     |
    | 0  cos φ    sin φ   |
    | 0 −sin φ    cos φ   |        φ = lean_deg
```

Consequences the script asserts after placement: the lid normal (box-local +Z) becomes
`(0, sin φ, cos φ)` — it tilts outboard; the stack axis (box-local +Y) becomes `(0, cos φ, −sin φ)`
— it descends outboard. The floor faces down and inboard, forming the channel roof. The inboard end
of the stack is the high end, nearest the centreline: the fuse bay and cable exits sit at the top of
the inverted V.

The **right box** is the placed left box mirrored through the plane Y = 0 (`mirror(about=Plane.XZ)`
in build123d). Nothing else is computed for it.

The **motor placeholder** is a cylinder of `housing_d` and `length` with its axis along
`[motor].axis` through `[motor].centre`. The **keep-out** is a cylinder of `[keepout].radius` along X
from `x_range[0]` to `x_range[1]` through `(axis_y, axis_z)`.

`placement.json` schema:

```json
{
  "params": {"x": 700.0, "y": 300.0, "z": 350.0, "lean_deg": 30.0},
  "left": {"corners": [[0, 0, 0], "... 8 outer-shell corners"], "lid_normal": [0, 0.5, 0.866], "stack_axis": [0, 0.866, -0.5]},
  "right": {"corners": [], "lid_normal": [0, -0.5, 0.866], "stack_axis": [0, -0.866, -0.5]},
  "motor": {"centre": [320, 0, 450], "axis": "Y", "d": 210.0, "length": 258.8},
  "keepout": {"axis_y": 0.0, "axis_z": 340.0, "radius": 60.0, "x_range": [400, 1200]},
  "inboard_gap_at_floor": 0.0
}
```

The example numbers above (`lean_deg = 30`, motor `axis = "Y"`) are illustrative of the mechanism
only. Section 4.6a carries the current committed values and what changed.

### 4.6a Owner corrections, 2026-09-17

Two corrections came out of a live session with the owner, checking placement against a
standalone three.js viewer (`docs/thrifty/2026-09-15-battery-boxes/artefacts/box-check-viewer.html`,
not a plan deliverable) because flat 2D renders proved unreliable for judging real clearance and
orientation. Full detail: `docs/thrifty/2026-09-15-battery-boxes/findings/WP-04.md`.

**Motor axis.** `[motor].axis` was `"Y"` (cross-vehicle) on the assumption of a cross-shaft
layout. The owner's notebook sketch and the LT-A400F propeller-shaft/differential reference
photos show the motor mounted in-line, fore-and-aft, parallel to the prop-shaft stack and
connected to it by a toothed belt (chain was a fallback note, not the design). Corrected to
`"X"`. This affects every clearance figure computed against the motor placeholder before
2026-09-17 in this document and in `findings/WP-04.md`.

**Box rotation reference.** The `[placement]` transform in section 4.6 rotates each box about
its **local origin** (the floor's inside-face centre). The owner's actual design reference is
different: each box pivots about its own **inner-most edge** — the longest edge (parallel to
X), the one with the 2nd-highest Z among the four box-local corner pairs (local Y =
`-outer_y/2`, Z = `-sheet`; floor side, inboard side). That edge's vehicle position is the
thing that should stay fixed as the lean angle changes, not the local origin.

`assembly.py` was not changed to implement this — a real hinge-pivot transform is a section 4.6
code change, not a parameter change, and is out of scope for whichever WP does it next. Instead,
the current `[placement]` x/y/z/lean_deg are **back-solved equivalents**: values that, through
the existing origin-based transform, put that inner-most edge at exactly the hinge position the
owner specified (vehicle Y = ±15 mm — a 30 mm gap — Z = 591.57 mm). This was verified against
`assembly.py`'s own `inboard_gap_at_floor` output (0.000 mm from 30.000 mm) after regenerating
`assembly.step` and `placement.json` through the real pipeline, not just asserted.

**Consequence for future changes.** Because these are back-solved equivalents, changing the gap
or the lean angle independently means re-solving x/y/z together (as `findings/WP-04.md` row 4
describes), not editing one field. If the hinge position needs to move independently of tilt
routinely, implement the hinge-pivot transform for real rather than keep back-solving.

**Not done.** The placement above is not verified clear of the frame - the owner deprioritised
collision-sweep precision in favour of getting real component CAD (motor, intermediate drive)
into the model. WP-04's formal sweep (section 4.7, items 5-11) has not run against this
placement. See `status/WP-04.md`.

`inboard_gap_at_floor` is the Y distance between the two boxes' inboard-bottom outer edges: the
channel width at its narrowest.

### 4.7 Clearance — `cad/clearance.py`

Runs under `.venv-mesh`. Loads `[chassis].mesh` into an Open3D `RaycastingScene` once. For one
placement `(x, y, z, lean)`:

| Step | Method |
|---|---|
| 1 Place | transform `box-shell.stl` by section 4.6 for the left box; mirror for the right |
| 2 Surface distance | sample `[sweep].samples` points uniformly on each box's surface; `scene.compute_distance` → `min_dist_left`, `min_dist_right` |
| 3 Frame inside the box | take chassis vertices inside each placed box's axis-aligned bounding box; build a `RaycastingScene` from the placed box; `compute_occupancy` → `inside_left`, `inside_right` (counts) |
| 4 Motor and keep-out | the same two tests for each box against the motor cylinder and the keep-out cylinder (each tessellated at 64 segments) |
| 5 Verdict | `pass` when every `inside` count is 0 and every minimum distance is at least `clearance_min` for the three box tests: frame, motor, keep-out |
| 6 Motor against the frame | computed once per run, not per placement, because the motor does not move in the sweep: `motor_frame_min` and `motor_frame_inside`, reported as their own line in `sweep-report.md` and never part of `pass` |

Controls, run first and printed, with these expected results from section 5.5:

| Control | Placement | Expect |
|---|---|---|
| Collision | (713, 300, 330, −30) | frame points inside the left box > 50 000; min distance < 1 mm |
| Clear | (700, 300, 1500, 30) | inside = 0; min distance > 200 mm |

The sweep evaluates every point of the `[sweep]` grid — 3 × 9 × 7 × 9 = 1 701 placements — and
writes `sweep.json` as a list of rows
`{x, y, z, lean, min_frame, inside_frame, min_motor, inside_motor, min_keepout, inside_keepout, pass}`,
with one top-level line for `motor_frame_min` and `motor_frame_inside` printed by the run.
`sweep-report.md` opens with the sentence "This sweep tests the frame, the placeholder motor and the
propeller-shaft keep-out only; plastics, foot boards, tank and seat are not in the scan." and then
tabulates, per X and per lean, the feasible Y and Z ranges and the best `min_frame`, names the
single best placement, states whether the `[placement]` defaults pass, and carries the motor
placeholder's own clearance to the frame as a separate line.

Section renders, for the `[placement]` defaults and for the best placement: project vertices of
`[chassis].mesh_1m` in a slab onto the section plane at 1 mm per pixel with a 100 mm grid, the axes
through the origin in red, and overlay both boxes' outer-shell edges, the motor and the keep-out in
colour. YZ section: slab X ∈ [x − 100, x + 100], viewed from the rear (+Y to the left of the image).
XZ: slab |Y| ≤ 450. XY: slab Z ∈ [150, 700]. PNG, under 500 kB each.

### 4.8 Mount pickups — `cad/mounts.py`

Runs under `.venv-mesh`. Inputs: `placement.json`, `box-shell.stl`, `[chassis].interfaces` and
`[chassis].primitives_engine_bay`. For every accepted cylinder in `interfaces.json` (all regions)
and every RANSAC plane in `primitives-engine-bay.json` with support over 1 500, compute the distance
from the primitive's point (cylinder) or centre (plane) to each placed box's shell, and keep those
under 120 mm. Write `mount-pickups.json` rows
`{id, kind, axis_or_normal, point, radius, length, support, rms, box, distance, nearest_face}`
where `nearest_face` is one of `floor, lid, inboard, outboard, front, rear`, sorted by distance.

`mounts-report.md` tabulates the rows and states the mounting concept as a fixed paragraph: two
locating pins on each box floor engaging bushes on brackets from the lower rails, and two
tensioners at the top, inboard, pulling the box down onto the pins and reached from above so their
mechanism is out of the mud. Bracket design is Sam's. The planes in the table were fitted by RANSAC
at 0.15–0.35 mm RMS but did not pass the pipeline's refinement threshold (section 5.1); each row
that is a plane carries the note "calliper before drilling".

### 4.9 Viewer and handover — `cad/viewer.py`

`viewer.html` is one file, no server, no build step. It loads exactly one external script,
`https://cdnjs.cloudflare.com/ajax/libs/three.js/r128/three.min.js` (measured reachable, section
5.6); orbit control is implemented inline (drag to rotate about the scene centre, wheel to zoom,
right-drag to pan) because the r128 examples are not on that CDN. Geometry is embedded as base64
Float32 triangle soups: the chassis decimated to 60 000 faces (2.9 MB as base64, section 5.6), both
box shells, the motor and the keep-out, tessellated from `assembly.step`. Each body has a checkbox;
a slider moves a YZ clipping plane along X. Axes triad and a 100 mm grid on the floor. File size
under 8 MB. Light background, chassis grey, boxes blue, motor orange, keep-out translucent red.

`sam-battery-boxes.html` follows the layout of
the chassis interface handover document `sam-chassis-interfaces.html` in the scan-pipeline plan's
artefacts directory (18 px base, single sheet, tables): purpose, the parameter table from `params.toml` with sources, the placement and the
transform in words, the sweep result and the best placement, the three default-placement renders
inline, the pickup table, links to the STEP files by relative path, and the open items (pad,
housing diameter, plastics scan, sheet thickness, compression wall, fuse envelope, keep-out). No
narrative about how the document was produced. Australian English.

### 4.10 Names and colours in every STEP file — `cad/common.py` and the three export scripts

Every body that goes into a STEP file has a `label` and a `color` (build123d attributes, set
before the body is placed in a `Compound`; section 5.9 shows both survive export and re-import).
`cad/common.py` gains one dictionary, `COLOURS`, mapping a colour name to `(r, g, b, alpha)` with
each channel 0 to 1; the three scripts read it and nothing else supplies colours. Geometry,
solid order, volumes and file names do not change.

| Colour name | RGB 0-1 | Alpha | Used by |
|---|---|---|---|
| `cell` | 0.31, 0.62, 0.42 | 1.0 | every cell |
| `shell` | 0.169, 0.424, 0.561 | 1.0 | `enclosure_body`, `box_left`, `box_right` |
| `lid` | 0.357, 0.608, 0.741 | 1.0 | `lid` |
| `plate` | 0.541, 0.604, 0.639 | 1.0 | `end_plate`, `partition`, `compression_plate` |
| `fuse` | 0.878, 0.690, 0.188 | 1.0 | `fuse_0`, `fuse_1` |
| `motor` | 0.851, 0.510, 0.169 | 1.0 | `motor` |
| `keepout` | 0.753, 0.224, 0.169 | 0.35 | `keepout` |
| `axis_x` | 0.80, 0.15, 0.15 | 1.0 | `axis_x` |
| `axis_y` | 0.15, 0.60, 0.25 | 1.0 | `axis_y` |
| `axis_z` | 0.15, 0.30, 0.80 | 1.0 | `axis_z` |

Labels, by file. The root label is the compound's own label; children keep the order shown.

| File | Root label | Child labels, in order |
|---|---|---|
| `cell.step` | `cell` | none: the root is the single solid |
| `block.step` | `block` | `cell_01` to `cell_26` |
| `box.step` | `box` | `enclosure_body`, `lid`, `end_plate`, `partition`, `compression_plate`, `fuse_0`, `fuse_1` |
| `box-full.step` | `box_full` | the seven above, then `block` holding `cell_01` to `cell_26` |
| `assembly.step` | `assembly` | `box_left`, `box_right`, `motor`, `keepout` |
| `data/cad/assembly-full.step` | `assembly_full` | the four above, then `left_cell_01` to `left_cell_26`, then `right_cell_01` to `right_cell_26` |

`assembly.step` keeps exactly four solids in the order `box_left`, `box_right`, `motor`, `keepout`:
`cad/viewer.py` raises if the count is not four or if solid 0 is not on the +Y side (WP-06), and
WP-07 must not edit `cad/viewer.py`.

Colour alpha is written into the STEP as `SURFACE_STYLE_TRANSPARENT(1 - alpha)` and is dropped on
a build123d re-import (section 5.9), so any check on alpha reads the STEP text, never a re-import.

### 4.11 The datum marker and the Fusion import workflow — `cad/fusion_pack.py`

**Frame.** Every STEP file in this plan is in the vehicle datum frame of the scan pipeline: ISO
8855, millimetres, X forward, Y left, Z up, origin below the rear axle housing axis
(`docs/thrifty/2026-09-14-scan-pipeline/plan.md`, the origin decision). The two battery boxes, the
motor and the keep-out sit at their vehicle coordinates in `assembly.step`; no file carries a
transform.

**The datum marker.** `artefacts/datum-marker.step` is three solid bars, each 20 mm square, one
corner on the origin, all in the positive quadrant:

| Label | Occupies | Colour | Length |
|---|---|---|---|
| `axis_x` | X 0 to 500, Y 0 to 20, Z 0 to 20 | `axis_x` | 500 mm |
| `axis_y` | X 0 to 20, Y 0 to 300, Z 0 to 20 | `axis_y` | 300 mm |
| `axis_z` | X 0 to 20, Y 0 to 20, Z 0 to 200 | `axis_z` | 200 mm |

The three lengths differ on purpose. A swapped axis shows as the wrong bar being longest, a
mirrored axis as a bar running into negative coordinates, a unit error as a factor of 25.4 or
1000, and a shifted origin as a bounding-box corner away from (0, 0, 0). The root label is
`datum_marker`.

**The workflow document.** `artefacts/fusion-import.html` is one self-contained HTML page (18 px
base font, one centred sheet of 1 220 px maximum width, plain tables, Australian English, no
external URL) with these sections in this order:

1. **What the files are.** A table of the six STEP files and the mesh, each with its purpose, and
   the frame statement above.
2. **Before you import.** Set the document to Z up, then import `datum-marker.step` alone, first,
   into an empty design.
3. **The origin and axis check.** A table of the pass criteria: the bounding box of each marker bar
   as Fusion reports it, the expected values from the table above, and the tolerance, 0.5 mm. If
   any value fails, stop and note the three observed bar lengths and which Fusion axis each lies
   along; do not rotate or move anything to make it pass.
4. **Import the assembly.** `assembly.step` into a new design in the same orientation. A table of
   the four bodies with name, colour and the expected bounding box in vehicle coordinates, computed
   by the script from the STEP file, not typed.
5. **Import the chassis.** The 200 k-face mesh `chassis_datum_200k.stl` as a mesh body, unit
   millimetres, with the expected bounding box: X -311.4 to 1663.0, Y -587.7 to 562.7, Z 4.3 to
   1206.1 mm (section 5.9), tolerance 1 mm. A factor of 25.4 means the wrong unit was chosen.
6. **Combine and look.** With the datum marker, the assembly and the chassis in one design and
   nothing moved, the marker's bars lie along the chassis' origin, the left box is on the +Y side,
   the motor is behind the boxes (smaller X), and the keep-out runs along X at Z 340 mm.
7. **Rules.** The CAD is the master: a placement or parameter change is made in `cad/params.toml`
   and regenerated, then re-imported. The placement is not verified clear of the frame
   (section 5.5 and the sweep report), and the plastics are not in the scan.
8. **Regenerate.** The commands to rebuild every file, from `cad/README.md`.

The document states procedure and pass criteria only. Fusion menu paths appear as the name of the
setting to look for, never as a click-by-click, because they differ between Fusion releases and
were not measured (section 5.9).

---

## 5. Measured constraints — measured 2026-09-15

All on the owner's workstation (i7-12700KF, 31.8 GB, Windows 11, Python 3.12). Commands were run
from the repo root.

### 5.1 The frame around the engine bay, from the datum-aligned mesh

Projections of `data/derived/chassis_datum_1M.stl` vertices onto YZ (X slabs), XZ and XY at 1 mm
per pixel, and the accepted primitives in `interfaces.json`:

| | |
|---|---|
| Bay is open (no frame points) for X 450–950, Z 320–590, all Y | YZ slabs 500–700, 700–900 |
| Lower rails, along X: r 14.3–14.9 mm at Y ±188 (X 611–630, Z 281), ±170 (X 760–771), ±145 (X 824, Z 279), ±131 (X 860), ±115 (X 901), ±71 (X 971–1003, Z 274–277) | accepted cylinders with axis within 25° of X |
| Rail top surface therefore at Z ≈ 296 | 281 + 15 |
| Upper rails: r 12.9 at Y ±120–125, Z 725–731 (X 500–560); Y ±64–72, Z 772–777 (X 676–701); Y ±98–145, Z 776–777 (X 853–1092) | same |
| Upper trapezoid in the X 500–700 slab: Y ±200 at Z 600 narrowing to ±110 at Z 780 | YZ slab 500–700 |
| Front downtubes converge from Y ±100 at Z 300 up to the front differential, X 900–1100 | YZ slab 900–1100 |
| Front differential output stub: a circle at Y ≈ +30, Z ≈ 350 in the X 900–1100 slab | same render; `[keepout].axis_z` default 340 derives from it and is an owner check |
| Rear cross-member on the floor: r 13.1 along Y at X 508, Z 284, length 372 | `engine-bay/cyl/013`, `cyl/029` |
| Engine-mount planes: normal Y at (454, +204, 362) support 14 975 rms 0.34 and (434, −206, 369) support 6 759 rms 0.30; normal Z at (643, −200, 300) support 5 446 rms 0.27 and (645, +199, 299) support 5 085 rms 0.18 | `primitives-engine-bay.json`, planes by support |
| Plane rows in `interfaces.json`: 123 in the engine bay, all `accepted: false` with refined rms 0.9–1.5 mm against the 0.5 mm threshold | `interfaces.json` |

**Rules that follow:**

1. Mount pickups come from the RANSAC plane table, not from `interfaces.json` planes, and every
   plane row says "calliper before drilling".
2. The keep-out height is an owner check, not a fact; the default is the render's reading.

### 5.2 build123d in `.venv-cad`

`.venv-cad` at the repo root imports build123d 0.11.1 (built this day from
`pipeline/requirements-cad.txt` with `python -m venv .venv-cad` then `pip install -r`).

| Operation | Time |
|---|---|
| `from build123d import *` | 3.0 s |
| Cell: box plus two stud cylinders | volume 406 850 mm³, bbox 148.24 × 26.66 × 105.9 |
| 26 cells as a `Compound` of moved copies | 0.0 s, bbox 452.24 × 247.94 × 105.9 at pitch 27.66 |
| Enclosure shell 466 × 306 × 203 minus cavity | 0.1 s, volume 1 208 988 mm³ |
| `export_step` cell, enclosure, and a 28-solid assembly | 0.1 s total; 23 437, 29 267 and 700 178 bytes |
| `export_gltf(binary=True)` of the assembly | 921 584 bytes |
| `import_step` of the assembly | 0.1 s, volume 12 214 878 mm³ |
| Whole spike script end to end | 3.9 s |

**Rules that follow:**

1. STEP files with the 26 cells are around 0.7 MB; the two-box assembly without cells is small.
   `assembly-full.step` (52 cells) goes to `data/cad/`; everything else in section 4.1 is committed.
2. No CAD item takes more than seconds. Budget is context, not wall clock.

### 5.3 FreeCAD as the lossless read path

`freecadcmd.exe` from `pipeline/config.local.toml` (`freecad_cmd`), on the same assembly STEP:

| | |
|---|---|
| `Part.read(step)`: solids, volume | 28 solids, 12 214 878 mm³, 0.66 s |
| build123d's own count and volume | 28 solids, 12 214 878 mm³ |

**Rules that follow:**

1. Every STEP export is verified by FreeCAD re-import: same solid count, volume within 0.01 %.
   `common.py` implements it once; every WP calls it and prints both numbers.

### 5.4 Chassis mesh state

| | |
|---|---|
| `data/derived/chassis_datum_5M.stl` | 4 021 243 triangles, 12 062 993 vertices as read by Open3D (the 5 M decimation, floor removed); 201 MB |
| `data/derived/chassis_datum_1M.stl` | 41 MB; 2 471 967 vertices as read by trimesh |
| `data/derived/chassis_datum_200k.stl` | 207 461 triangles, 10.4 MB |
| `.venv-mesh` at the repo root | imports open3d 0.19.0 and trimesh 5.1.0 |

**Rules that follow:**

1. The sweep body count is 4 021 243 faces; a script that asserts "5 000 000" fails.
2. Both venvs at the repo root work. Do not create venvs elsewhere.

### 5.5 Clearance evaluation and the sweep

Open3D `RaycastingScene` on `chassis_datum_5M.stl`; box outer shell 466 × 306 × 206; the transform
of section 4.6.

| | |
|---|---|
| Read the 5 M mesh and build the BVH | 5.8 s |
| 20 000 surface samples, `compute_distance` | 1.15 s first call, then under 0.1 s |
| Occupancy of the chassis vertices inside the placed box's bounding box | 0.01 s |
| Control, collision (713, 300, 330, lean −30) | 70 550 chassis points inside the box; min distance 0.01 mm |
| Control, clear (700, 300, 1500, lean 30) | 0 inside; min distance 233.9 mm |
| Sweep: 567 placements at X 700, lean 0–40 step 5, Y 200–400 step 25, Z 300–450 step 25, 8 000 samples | 122.9 s |
| Feasible (0 inside, ≥ 10 mm): 216 of 567 | |
| Lean 0: Y 375–400 · lean 15: Y 325–400 · lean 30: Y 275–400 · lean 40: Y 275–400; Z 300–450 feasible at every lean | |
| Best frame clearance: lean 10, Y 400, Z 450, 61.5 mm; lean 30 best 52.1 mm at Y 400, Z 450 | |

**Rules that follow:**

1. The full grid of section 4.7 (1 701 placements) costs about 6.5 minutes. Run it once as one
   item, in the foreground, with a 15-minute timeout.
2. The bare frame admits every lean from 0 to 40°. The report must say so and must say that the
   plastics are the missing constraint; a session must not present the frame result as a fit.
3. `[placement]` defaults (700, 300, 350, 30) lie inside the feasible set at 10 mm.

### 5.6 Viewer assets

| | |
|---|---|
| `https://cdnjs.cloudflare.com/ajax/libs/three.js/r128/three.min.js` | HTTP 200, 603 445 bytes |
| `https://cdnjs.cloudflare.com/ajax/libs/three.js/r128/examples/js/controls/OrbitControls.js` and the matching `STLLoader.js` | HTTP 404 — not on that CDN |
| Decimate the 200 k mesh to 100 000 faces (Open3D quadric) | 1.0 s; Float32 soup 3.6 MB; base64 4.8 MB |
| Decimate to 60 000 faces | 1.1 s; 2.2 MB; base64 2.9 MB |

**Rules that follow:**

1. Orbit control is written inline. No second CDN script.
2. The viewer embeds the 60 000-face chassis and stays under 8 MB.

### 5.7 Electrical parts from the BOM and datasheets

| | |
|---|---|
| Cells purchased | 60 (52 fitted, 8 spare); "1C – 8C 10 s"; pack 26S2P, 96.2 V nominal, 113.1 V max | EB-Quad BOM sheet |
| Fuses | 4 × Littelfuse JLLN800 Class T with holders; datasheet DC rating 125 V for 70–1 200 A; 700–800 A dimension row A = 85.7 mm, B = 56.4 mm | BOM; datasheet page 2 and the dimension table |
| Contactors | 4 × TE LEV200, 500 A, bottom mount, M8 terminals — central box, not in the battery boxes | BOM; TE datasheet |
| BMS | ANT 21–30S — central, sense leads from each box | BOM |
| Motor | BOM lists "QS138 90H V1 (QSD138A-90)"; the outline drawing supplied is SIAECOSYS QSJ138D-90-4000W: 258.8 long, 131 bolt circle, 120 spigot, Ø20 spline; housing diameter not dimensioned in the visible text | BOM; drawing |

**Rules that follow:**

1. Two fuse envelopes per box. Their size is the parameter; the owner confirms it with the holder in
   hand.
2. The motor housing diameter is a placeholder until measured.

### 5.8 Per-item cost — what sets every item cap

An item is one script function or stage: write or adapt it, run it, read its output, record the
result. Measured on this session's own spikes:

| | |
|---|---|
| Script per item (`wc -c` on the CAD spike) | 2 263 bytes, about 570 tokens |
| Run output per item | 15–25 lines, about 250 tokens; the sweep summary about 600 |
| Status and batch report per item | about 500 tokens |
| Reasoning allowance | 2 000 tokens |
| Measured cost of one item | 4 000 tokens |
| Working budget (half a 200 k window) | 100 000 tokens |
| **Item cap per session** | **25** |

**Rules that follow:**

1. No work package exceeds 25 items. Every WP below has 12 or fewer.
2. Reaching the cap is a normal ending: `state: paused`, `resume-from` set, and the same starter
   prompt resumes it.
3. Never read a STEP file, a sweep JSON or a mesh into context. Read counts, the first twenty rows,
   and the script's own summary lines.

### 5.9 Names, colours and Fusion

Measured 2026-10-05 in `.venv-cad` (rebuilt in place from `pipeline/requirements-cad.txt`,
build123d 0.11.1), on the STEP files merged by WP-06.

| | |
|---|---|
| Every committed STEP file today: unit, product names, colours | `SI_UNIT(.MILLI.,.METRE.)` in all five; every `PRODUCT(` name is `COMPOUND`; `COLOUR_RGB` count 0 (grep on `cell`, `block`, `box`, `box-full`, `assembly`) |
| Baselines before any change: solids, volume, bytes | `cell.step` 1, 406 850.1 mm3, 24 037 · `block.step` 26, 10 578 102.1, 624 555 · `box.step` 7, 3 186 335.6, 346 820 · `box-full.step` 33, 13 764 437.7, 988 797 · `assembly.step` 4, 76 761 150.9, 46 646 (`freecad_check` from `cad/common.py`) |
| Label and colour on children of a `Compound`, `export_step`, then grep and re-import | `PRODUCT` names `['assembly', 'box_left', 'motor']`; `COLOUR_RGB` count 3; re-import returns the labels and colours; `freecad_check` returns `(2, 175398.22)`, the right solid count and volume |
| Colour alpha in STEP | `SURFACE_STYLE_TRANSPARENT(0.65000000596)` for alpha 0.35 appears in the file; re-import through build123d returns alpha 1.0, so the alpha is lost on that path |
| `box-full.step` margin under the 1 MB cap | 988 797 bytes, 11 KB under; names and 33 colour records push it over, hence the 1.5 MB cap in section 2 |
| Chassis mesh bounding box, `data/derived/chassis_datum_200k.stl`, Open3D vertices | min (-311.38, -587.73, 4.31), max (1663.02, 562.66, 1206.14) mm |
| `cad/viewer.py` dependence on `assembly.step` | raises unless there are exactly four solids and solid 0 has centre Y > 0 and solid 1 centre Y < 0 (`cad/viewer.py` lines 102 and 108) |
| `pipeline/config.local.toml` in a fresh worktree | absent: it is git-ignored, so `freecad_check` fails with `FileNotFoundError` until the file is copied from the owner's main checkout |
| Fusion installed on the owner's workstation | `Fusion360.exe` present under `AppData/Local/Autodesk/webdeploy/production/`; the Fusion API folder is present under `AppData/Roaming/Autodesk/Autodesk Fusion 360/API/` |

**Not measured.** How Fusion treats these files has not been run on any machine. The Autodesk
support article on Fusion's modelling orientation returned HTTP 403, and a web search returned
only forum and summary text that disagreed on which orientation is the default and said the
orientation setting applies to new designs only. So nothing in this plan states what Fusion does
with Z up, with the origin, or with colour and transparency on import. That is why
`datum-marker.step` exists: the owner imports it first and reads three numbers.

**Rules that follow:**

1. Verify a name by grepping the STEP text for `PRODUCT('<name>'`, and a colour by grepping for
   `COLOUR_RGB`; verify alpha by grepping for `SURFACE_STYLE_TRANSPARENT`. A build123d re-import
   proves names and colours but not alpha.
2. Names and colours must not change a solid count or a volume. `freecad_check` against the
   baselines above is the proof, and `git diff --stat` showing only STEP files changed is the
   second proof.
3. Item cost is as in 5.8; WP-07 has 11 items.

---
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

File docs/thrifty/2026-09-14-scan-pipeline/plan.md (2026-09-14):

# Scan pipeline: toolsets, condition, crop, segment, fit — Plan

| Property | Value |
|---|---|
| Date | 2026-09-14 |
| Owner | Jeremy |
| Repo | electric-butterfly/equad |
| Tier | 2 Sub-project |
| Status | Draft |

---

## 1. Purpose

The eQuad conversion is a packaging problem on a machine whose geometry exists only as an Artec
scan: 35,074,344 triangles of the stripped rolling chassis in a frame of the scanner's choosing,
with the workshop floor attached. Nothing downstream — the intermediate drive, the battery boxes,
the controller box, the ducting — can be drawn until that scan is cleaned, aligned to a vehicle
datum, cropped to the regions a new part touches, and its tube runs and mount plates reduced to
geometric primitives with known residuals.
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

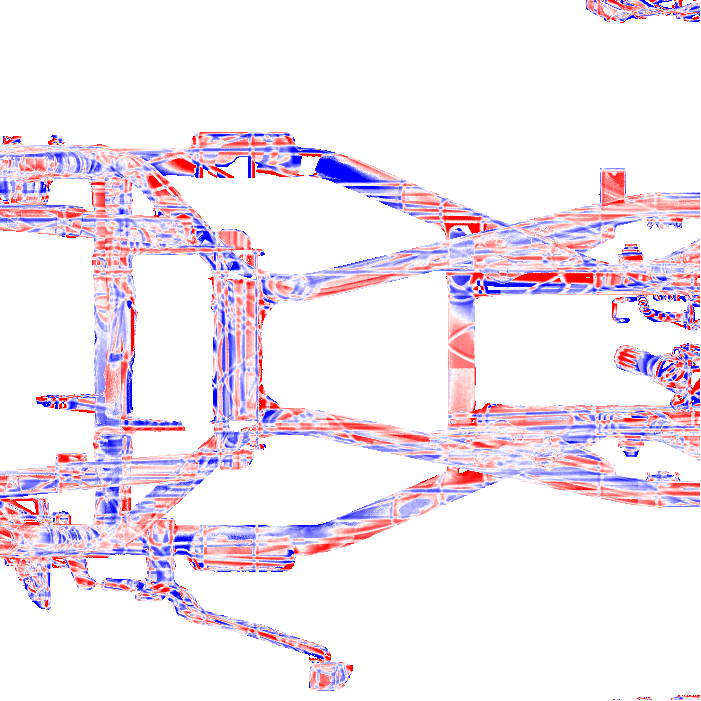
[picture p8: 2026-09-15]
docs/thrifty/2026-09-14-scan-pipeline/artefacts/deviation-engine-bay.png

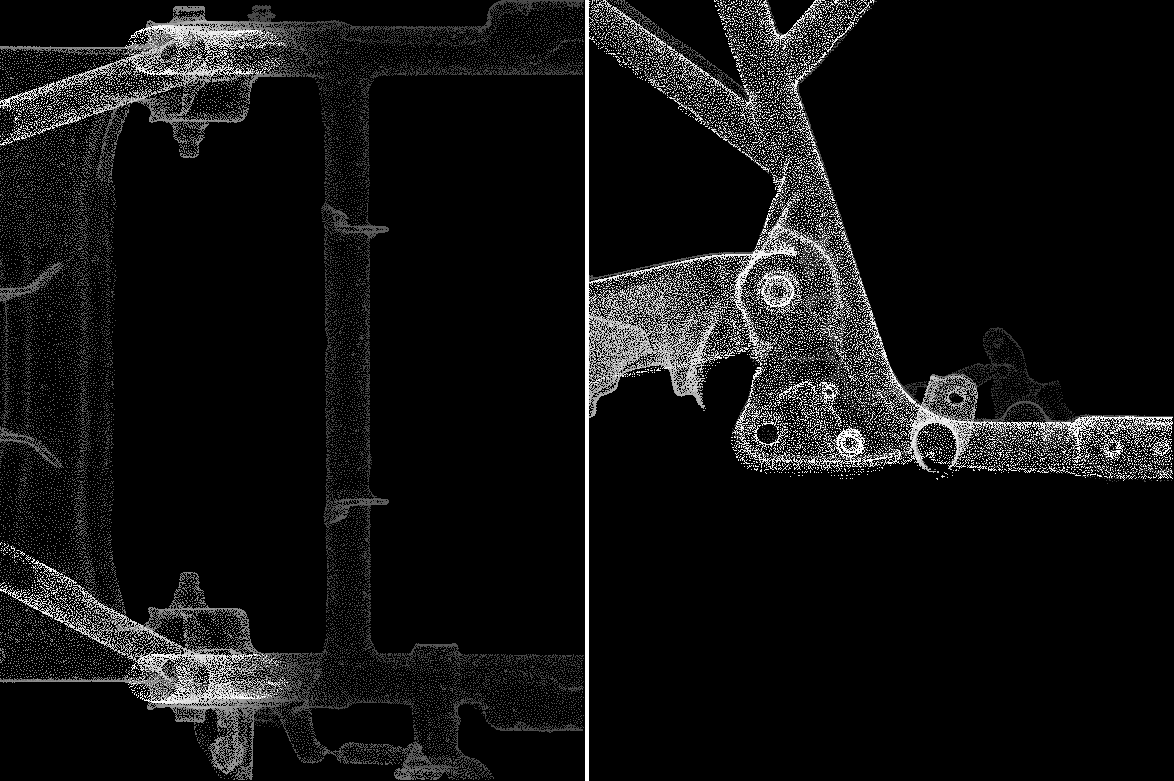
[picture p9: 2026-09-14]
docs/thrifty/2026-09-14-scan-pipeline/artefacts/crop-rear-flange.png

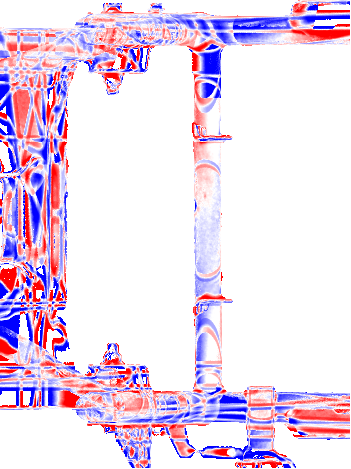
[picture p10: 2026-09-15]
docs/thrifty/2026-09-14-scan-pipeline/artefacts/deviation-rear-flange.png

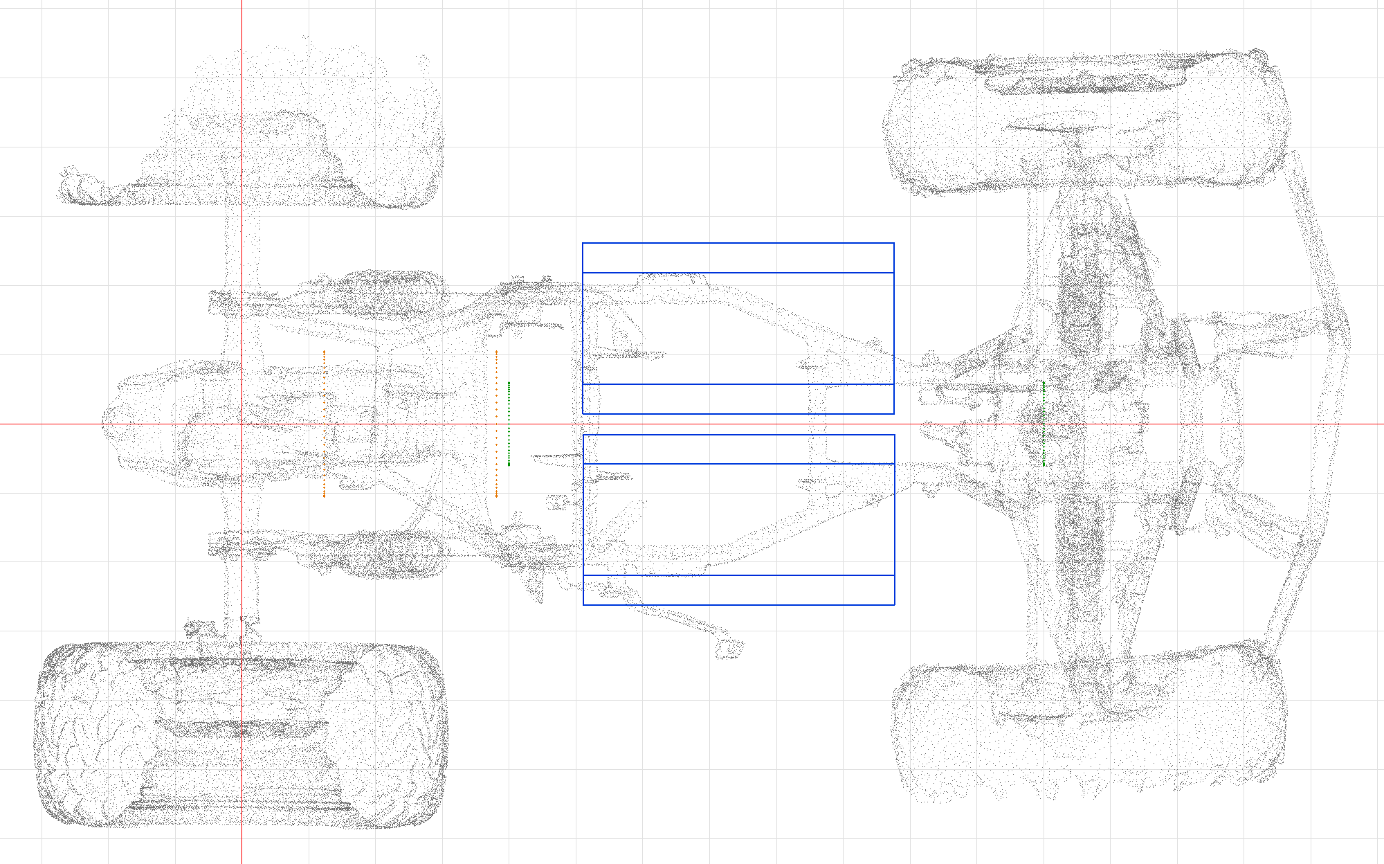
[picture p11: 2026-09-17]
docs/thrifty/2026-09-15-battery-boxes/artefacts/section-xy-default.png

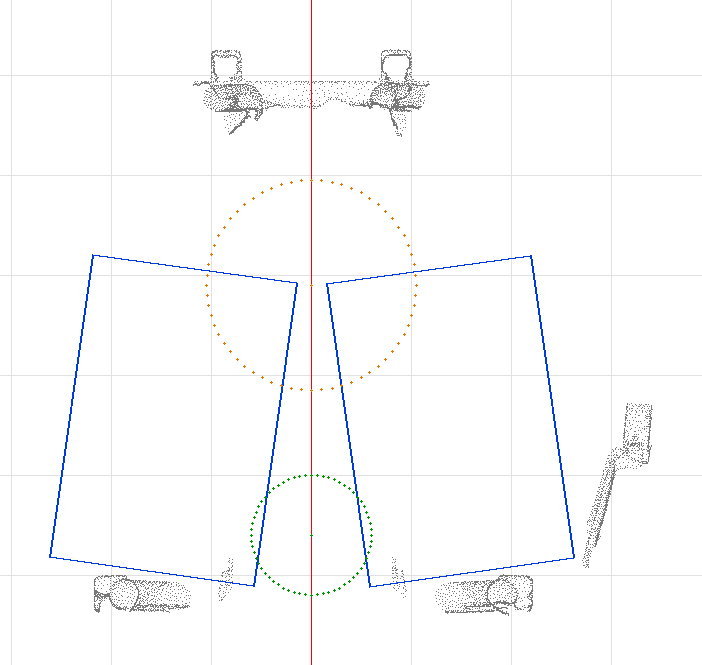
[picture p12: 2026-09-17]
docs/thrifty/2026-09-15-battery-boxes/artefacts/section-yz-default.png

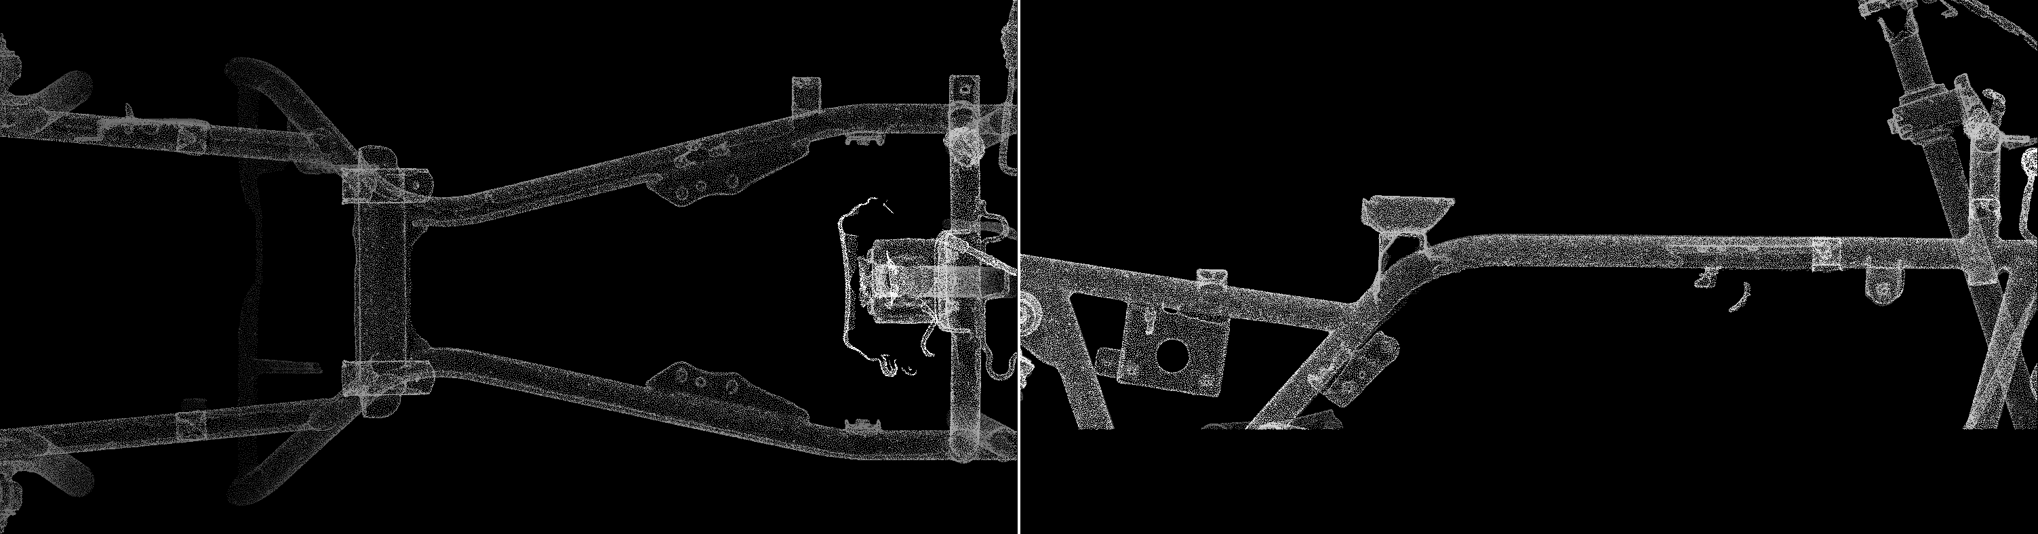
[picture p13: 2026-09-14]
docs/thrifty/2026-09-14-scan-pipeline/artefacts/crop-tank-mounts.png

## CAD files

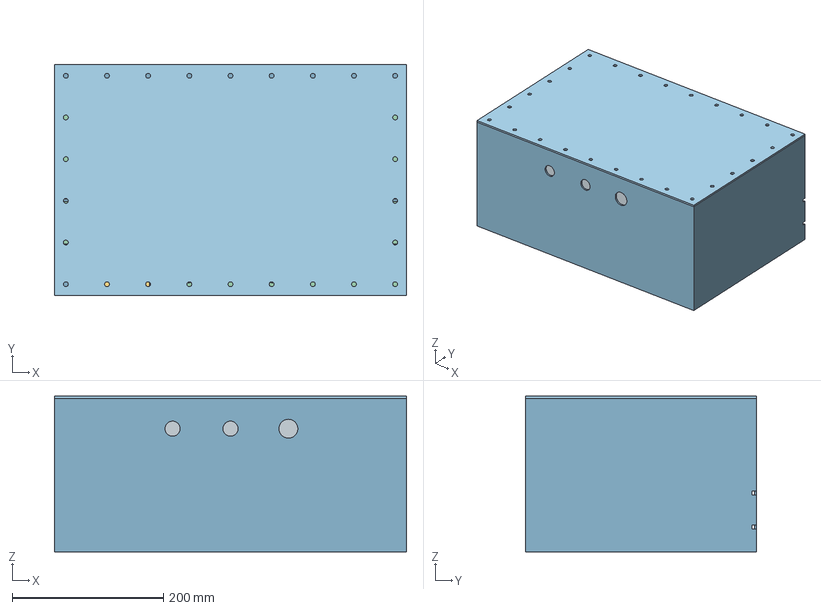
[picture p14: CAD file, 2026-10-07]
docs/thrifty/2026-09-15-battery-boxes/artefacts/box-full.step
466.0 x 306.0 x 206.0 mm
enclosure_body
lid
end_plate
partition
compression_plate
fuse_0
fuse_1
cell_01
cell_02
cell_03
cell_04
cell_05
cell_06
cell_07
cell_08
cell_09
cell_10
cell_11
cell_12
cell_13
cell_14
cell_15
cell_16
cell_17
cell_18
cell_19
cell_20
cell_21
cell_22
cell_23
cell_24
cell_25
cell_26

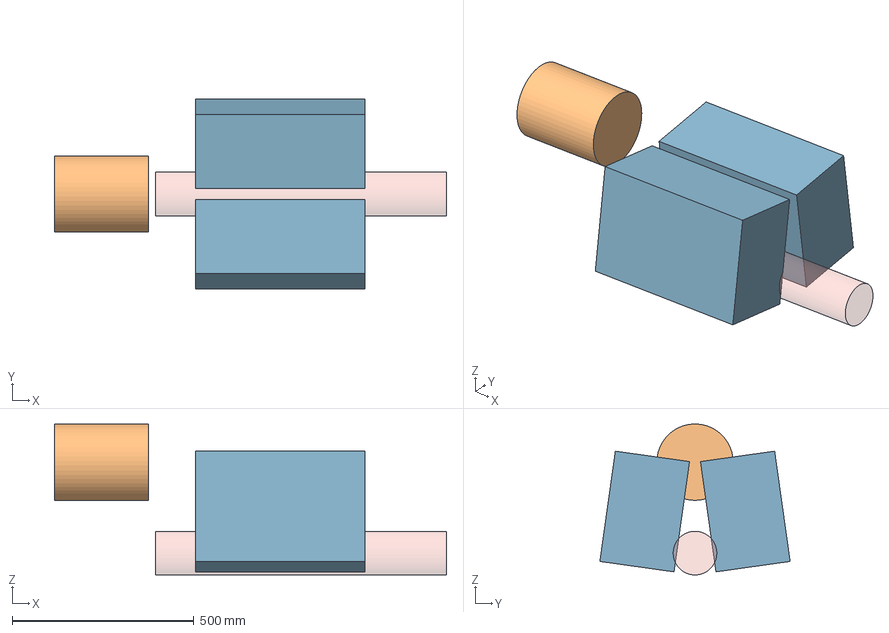
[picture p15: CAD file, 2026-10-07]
docs/thrifty/2026-09-15-battery-boxes/artefacts/assembly.step
1077.4 x 523.2 x 414.8 mm
box_left
box_right
motor
keepout

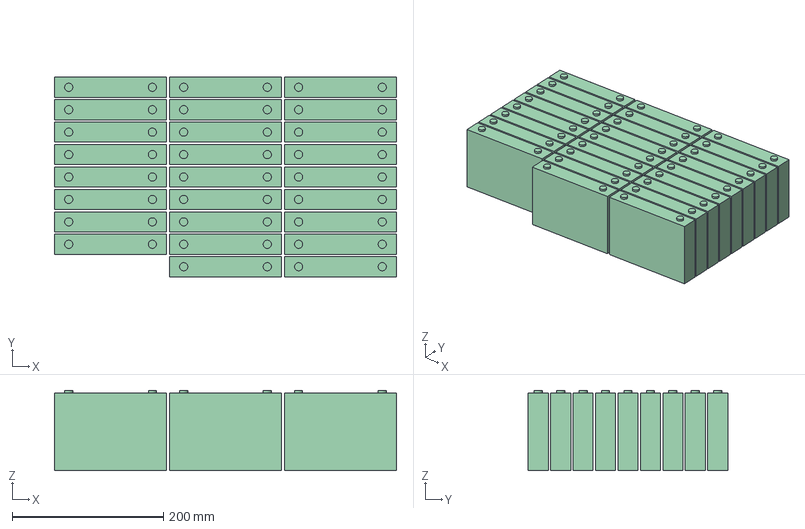
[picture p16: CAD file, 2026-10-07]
docs/thrifty/2026-09-15-battery-boxes/artefacts/block.step
452.2 x 263.9 x 105.9 mm
cell_01
cell_02
cell_03
cell_04
cell_05
cell_06
cell_07
cell_08
cell_09
cell_10
cell_11
cell_12
cell_13
cell_14
cell_15
cell_16
cell_17
cell_18
cell_19
cell_20
cell_21
cell_22
cell_23
cell_24
cell_25
cell_26

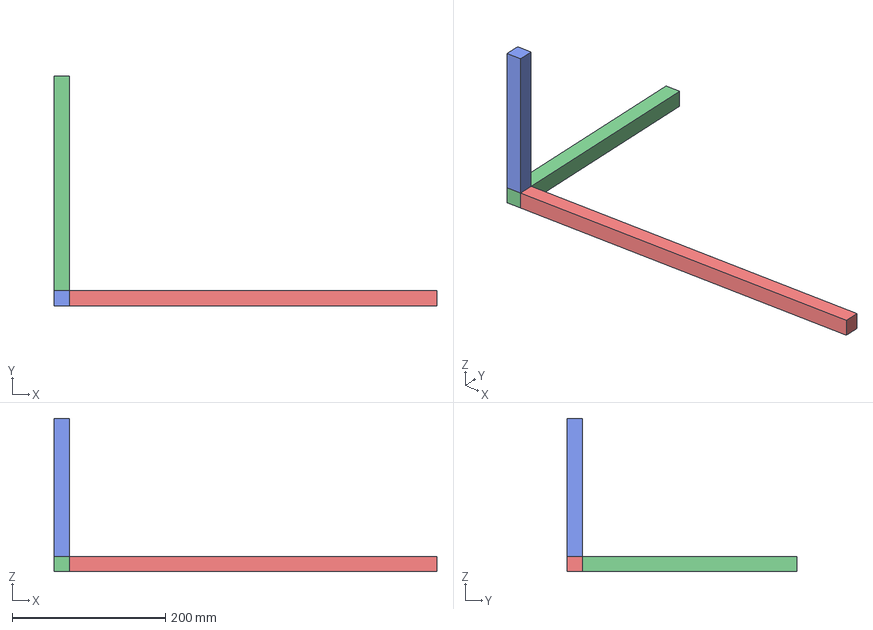
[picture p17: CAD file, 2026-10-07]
docs/thrifty/2026-09-15-battery-boxes/artefacts/datum-marker.step
500.0 x 300.0 x 200.0 mm
axis_x
axis_y
axis_z

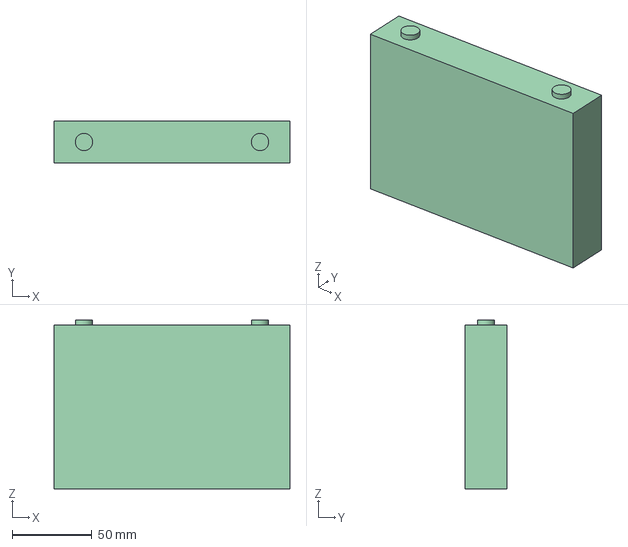
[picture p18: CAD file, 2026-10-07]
docs/thrifty/2026-09-15-battery-boxes/artefacts/cell.step
148.2 x 26.7 x 105.9 mm

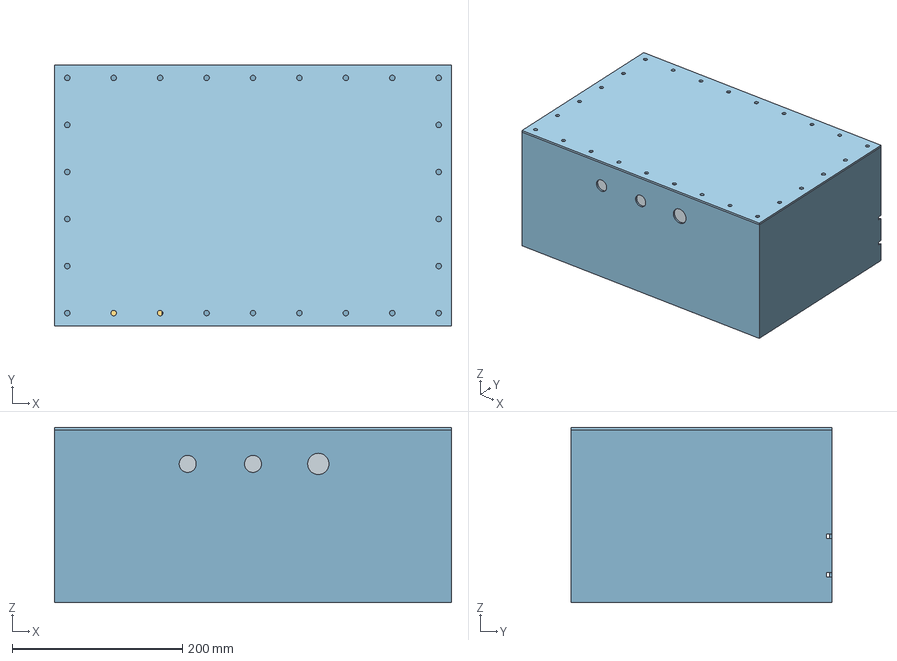
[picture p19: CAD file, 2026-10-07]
docs/thrifty/2026-09-15-battery-boxes/artefacts/box.step
466.0 x 306.0 x 206.0 mm
enclosure_body
lid
end_plate
partition
compression_plate
fuse_0
fuse_1

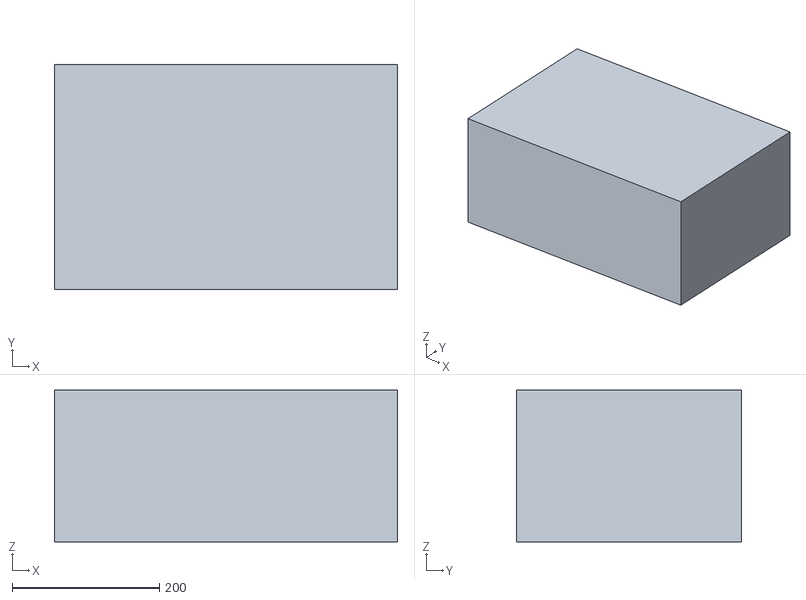
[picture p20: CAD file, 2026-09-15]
docs/thrifty/2026-09-15-battery-boxes/artefacts/box-shell.stl
466.0 x 306.0 x 206.0

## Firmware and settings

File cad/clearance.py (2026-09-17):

"""Clearance evaluation, the sweep and section renders against the datum-aligned frame mesh.

Runs under .venv-mesh. Plan section 4.7: for one placement (x, y, z, lean) of the two boxes,
test surface distance and point-inside-solid occupancy against the frame, the placeholder motor
and the propeller-shaft keep-out.
"""

import argparse
import json
import time
from pathlib import Path

import numpy as np
import open3d as o3d
import trimesh

from common import artefacts_dir, load_params, repo_root

SAMPLE_SEED = 42


# ---------------------------------------------------------------------------
# The section 4.6 transform, in numpy
# ---------------------------------------------------------------------------

def left_matrix(lean_deg: float) -> np.ndarray:
    """R of section 4.6: local +Z -> (0, sin phi, cos phi), local +Y -> (0, cos phi, -sin phi)."""
    phi = np.radians(lean_deg)
    return np.array(
        [
            [1.0, 0.0, 0.0],
            [0.0, np.cos(phi), np.sin(phi)],
            [0.0, -np.sin(phi), np.cos(phi)],
        ]
    )


def place_vertices(local_verts: np.ndarray, x: float, y: float, z: float, lean_deg: float, side: str) -> np.ndarray:
    """p_vehicle = [x, y, z] + R . p_local for the left box; the right box mirrors through Y = 0."""
    R = left_matrix(lean_deg)
    placed = local_verts @ R.T + np.array([x, y, z])
    if side == "right":
        placed = placed * np.array([1.0, -1.0, 1.0])
    return placed


# ---------------------------------------------------------------------------
# The frame mesh (loaded once)
# ---------------------------------------------------------------------------

def load_scene(params: dict) -> tuple[o3d.t.geometry.RaycastingScene, np.ndarray, int, int]:
    """Read [chassis].mesh into an Open3D RaycastingScene. Returns (scene, vertices, n_verts, n_faces)."""
    mesh_path = repo_root() / params["chassis"]["mesh"]
    if not mesh_path.exists():
        raise FileNotFoundError(f"chassis mesh not found: {mesh_path}")
    mesh = o3d.t.io.read_triangle_mesh(str(mesh_path))
    verts = mesh.vertex.positions.numpy()
    n_verts = verts.shape[0]
    n_faces = mesh.triangle.indices.shape[0]
    scene = o3d.t.geometry.RaycastingScene()
    scene.add_triangles(mesh)
    return scene, verts, n_verts, n_faces


# ---------------------------------------------------------------------------
# The box shell: local mesh, local surface samples, per-placement transform
# ---------------------------------------------------------------------------

_SHELL_CACHE: dict[float, trimesh.Trimesh] = {}
_SAMPLE_CACHE: dict[tuple[float, int], np.ndarray] = {}


def chamfer_shell(mesh: trimesh.Trimesh, params: dict, leg: float) -> trimesh.Trimesh:
    """Cut a 45 deg chamfer of the given leg length on the box-local +X/+Z top edge (plan 4.5),
    by slicing the shell with the chamfer plane and capping the cut face."""
    e = params["enclosure"]
    outer_x = e["internal"][0] + 2 * e["sheet"]
    top_z = e["internal"][2] + e["sheet"]
    x_edge = outer_x / 2
    plane_origin = np.array([x_edge - leg, 0.0, top_z])
    plane_normal = np.array([1.0, 0.0, 1.0]) / np.sqrt(2)
    # keep the side away from the corner being chamfered off
    return mesh.slice_plane(plane_origin, -plane_normal, cap=True)


def get_shell_mesh(params: dict, chamfer_leg: float = 0.0) -> trimesh.Trimesh:
    key = round(chamfer_leg, 3)
    if key not in _SHELL_CACHE:
        path = artefacts_dir() / "box-shell.stl"
        if not path.exists():
            raise FileNotFoundError(f"box-shell.stl not found: {path}")
        mesh = trimesh.load(path, process=True)
        if key > 0:
            mesh = chamfer_shell(mesh, params, key)
        _SHELL_CACHE[key] = mesh
    return _SHELL_CACHE[key]


def get_local_samples(params: dict, n: int, chamfer_leg: float = 0.0) -> np.ndarray:
    key = (round(chamfer_leg, 3), n)
    if key not in _SAMPLE_CACHE:
        mesh = get_shell_mesh(params, chamfer_leg)
        pts, _ = trimesh.sample.sample_surface(mesh, n, seed=SAMPLE_SEED)
        _SAMPLE_CACHE[key] = np.asarray(pts)
    return _SAMPLE_CACHE[key]


def placed_shell_o3d(params: dict, x: float, y: float, z: float, lean_deg: float, side: str,
                      chamfer_leg: float = 0.0) -> o3d.t.geometry.TriangleMesh:
    mesh = get_shell_mesh(params, chamfer_leg)
    verts = place_vertices(np.asarray(mesh.vertices), x, y, z, lean_deg, side)
    faces = np.asarray(mesh.faces)
    m = o3d.t.geometry.TriangleMesh()
    m.vertex.positions = o3d.core.Tensor(verts.astype(np.float32))
    m.triangle.indices = o3d.core.Tensor(faces.astype(np.int32))
    return m


# ---------------------------------------------------------------------------
# Motor and keep-out cylinders (fixed for the whole sweep)
# ---------------------------------------------------------------------------

def _cylinder_mesh(radius: float, length: float, axis: str, centre) -> trimesh.Trimesh:
    cyl = trimesh.creation.cylinder(radius=radius, height=length, sections=64)
    if axis == "Y":
        cyl.apply_transform(trimesh.transformations.rotation_matrix(np.radians(90), [1, 0, 0]))
    elif axis == "X":
        cyl.apply_transform(trimesh.transformations.rotation_matrix(np.radians(90), [0, 1, 0]))
    cyl.apply_translation(centre)
    return cyl


def motor_mesh(params: dict) -> trimesh.Trimesh:
    m = params["motor"]
    return _cylinder_mesh(m["housing_d"] / 2, m["length"], m["axis"], m["centre"])


def keepout_mesh(params: dict) -> trimesh.Trimesh:
    k = params["keepout"]
    x_lo, x_hi = k["x_range"]
    length = x_hi - x_lo
    x_mid = (x_lo + x_hi) / 2
    return _cylinder_mesh(k["radius"], length, "X", [x_mid, k["axis_y"], k["axis_z"]])


def trimesh_to_o3d(tm: trimesh.Trimesh) -> o3d.t.geometry.TriangleMesh:
    m = o3d.t.geometry.TriangleMesh()
    m.vertex.positions = o3d.core.Tensor(np.asarray(tm.vertices, dtype=np.float32))
    m.triangle.indices = o3d.core.Tensor(np.asarray(tm.faces, dtype=np.int32))
    return m


def scene_from_mesh(mesh: o3d.t.geometry.TriangleMesh) -> o3d.t.geometry.RaycastingScene:
    s = o3d.t.geometry.RaycastingScene()
    s.add_triangles(mesh)
    return s


# ---------------------------------------------------------------------------
# Distance and occupancy primitives
# ---------------------------------------------------------------------------

def min_distance(scene: o3d.t.geometry.RaycastingScene, points: np.ndarray) -> float:
    q = o3d.core.Tensor(points.astype(np.float32))
    d = scene.compute_distance(q).numpy()
    return float(d.min())


def inside_count(box_scene: o3d.t.geometry.RaycastingScene, candidate_verts: np.ndarray,
                  aabb_min: np.ndarray, aabb_max: np.ndarray) -> int:
    mask = np.all((candidate_verts >= aabb_min) & (candidate_verts <= aabb_max), axis=1)
    inside_aabb = candidate_verts[mask]
    if inside_aabb.shape[0] == 0:
        return 0
    q = o3d.core.Tensor(inside_aabb.astype(np.float32))
    occ = box_scene.compute_occupancy(q).numpy()
    return int(occ.sum())


# ---------------------------------------------------------------------------
# evaluate(): section 4.7 steps 1-5 for one placement; motor_vs_frame(): step 6
# ---------------------------------------------------------------------------

def evaluate(params: dict, x: float, y: float, z: float, lean_deg: float,
             chassis_scene, chassis_verts: np.ndarray,
             motor_scene, motor_verts: np.ndarray,
             keepout_scene, keepout_verts: np.ndarray,
             n_samples: int, clearance_min: float, chamfer_leg: float = 0.0) -> dict:
    local_samples = get_local_samples(params, n_samples, chamfer_leg)

    min_frame = min_motor = min_keepout = float("inf")
    inside_frame = inside_motor = inside_keepout = 0

    for side in ("left", "right"):
        placed_samples = place_vertices(local_samples, x, y, z, lean_deg, side)
        box_mesh = placed_shell_o3d(params, x, y, z, lean_deg, side, chamfer_leg)
        box_scene = scene_from_mesh(box_mesh)
        box_verts = box_mesh.vertex.positions.numpy()
        aabb_min = box_verts.min(axis=0)
        aabb_max = box_verts.max(axis=0)

        min_frame = min(min_frame, min_distance(chassis_scene, placed_samples))
        inside_frame += inside_count(box_scene, chassis_verts, aabb_min, aabb_max)

        min_motor = min(min_motor, min_distance(motor_scene, placed_samples))
        inside_motor += inside_count(box_scene, motor_verts, aabb_min, aabb_max)

        min_keepout = min(min_keepout, min_distance(keepout_scene, placed_samples))
        inside_keepout += inside_count(box_scene, keepout_verts, aabb_min, aabb_max)

    passed = (
        inside_frame == 0 and min_frame >= clearance_min
        and inside_motor == 0 and min_motor >= clearance_min
        and inside_keepout == 0 and min_keepout >= clearance_min
    )

    return {
        "x": x, "y": y, "z": z, "lean": lean_deg,
        "min_frame": round(min_frame, 3), "inside_frame": inside_frame,
        "min_motor": round(min_motor, 3), "inside_motor": inside_motor,
        "min_keepout": round(min_keepout, 3), "inside_keepout": inside_keepout,
        "pass": passed,
    }


def motor_vs_frame(params: dict, chassis_scene, chassis_verts: np.ndarray,
                    motor_scene, motor_mesh_tm: trimesh.Trimesh, n_samples: int) -> tuple[float, int]:
    """Section 4.7 step 6: the motor placeholder's own clearance to the frame, computed once."""
    pts, _ = trimesh.sample.sample_surface(motor_mesh_tm, n_samples, seed=SAMPLE_SEED)
    motor_frame_min = min_distance(chassis_scene, np.asarray(pts))

    motor_o3d = trimesh_to_o3d(motor_mesh_tm)
    motor_scene_ray = scene_from_mesh(motor_o3d)
    verts = motor_o3d.vertex.positions.numpy()
    aabb_min = verts.min(axis=0)
    aabb_max = verts.max(axis=0)
    motor_frame_inside = inside_count(motor_scene_ray, chassis_verts, aabb_min, aabb_max)
    return round(motor_frame_min, 3), motor_frame_inside


# ---------------------------------------------------------------------------
# Controls (plan section 4.7 table) -- the canary
# ---------------------------------------------------------------------------

CONTROLS = {
    "collision": {"x": 713.0, "y": 300.0, "z": 330.0, "lean": -30.0, "expect": "inside > 50000, min_frame < 1.0"},
    "clear": {"x": 700.0, "y": 300.0, "z": 1500.0, "lean": 30.0, "expect": "inside = 0, min_frame > 200"},
}


def run_controls(params: dict) -> None:
    print("loading chassis scene...")
    t0 = time.time()
    chassis_scene, chassis_verts, n_verts, n_faces = load_scene(params)
    print(f"chassis: {n_faces} faces, {n_verts} vertices ({time.time() - t0:.1f}s)")

    motor_tm = motor_mesh(params)
    keepout_tm = keepout_mesh(params)
    motor_scene = scene_from_mesh(trimesh_to_o3d(motor_tm))
    keepout_scene = scene_from_mesh(trimesh_to_o3d(keepout_tm))
    motor_o3d = trimesh_to_o3d(motor_tm)
    keepout_o3d = trimesh_to_o3d(keepout_tm)
    motor_verts = motor_o3d.vertex.positions.numpy()
    keepout_verts = keepout_o3d.vertex.positions.numpy()

    n_samples = params["sweep"]["samples"]
    clearance_min = params["placement"]["clearance_min"]

    for name, c in CONTROLS.items():
        t0 = time.time()
        row = evaluate(
            params, c["x"], c["y"], c["z"], c["lean"],
            chassis_scene, chassis_verts, motor_scene, motor_verts, keepout_scene, keepout_verts,
            n_samples, clearance_min,
        )
        print(f"{name} ({c['x']}, {c['y']}, {c['z']}, {c['lean']}): {row} [{time.time() - t0:.2f}s] expect {c['expect']}")

    mf_min, mf_inside = motor_vs_frame(params, chassis_scene, chassis_verts, motor_scene, motor_tm, n_samples)
    print(f"motor_frame_min: {mf_min} mm, motor_frame_inside: {mf_inside}")


# ---------------------------------------------------------------------------
# Sweep grid, full sweep, summary
# ---------------------------------------------------------------------------

def sweep_grid(sweep_params: dict) -> list[tuple[float, float, float, float]]:
    xs = sweep_params["x"]
    y0, y1, ys = sweep_params["y_range"]
    z0, z1, zs = sweep_params["z_range"]
    l0, l1, ls = sweep_params["lean_range"]
    ys_list = np.round(np.arange(y0, y1 + ys / 2, ys), 6).tolist()
    zs_list = np.round(np.arange(z0, z1 + zs / 2, zs), 6).tolist()
    ls_list = np.round(np.arange(l0, l1 + ls / 2, ls), 6).tolist()
    return [(x, y, z, l) for x in xs for y in ys_list for z in zs_list for l in ls_list]


def _build_scenes(params: dict):
    chassis_scene, chassis_verts, n_verts, n_faces = load_scene(params)
    motor_tm = motor_mesh(params)
    keepout_tm = keepout_mesh(params)
    motor_o3d = trimesh_to_o3d(motor_tm)
    keepout_o3d = trimesh_to_o3d(keepout_tm)
    motor_scene = scene_from_mesh(motor_o3d)
    keepout_scene = scene_from_mesh(keepout_o3d)
    motor_verts = motor_o3d.vertex.positions.numpy()
    keepout_verts = keepout_o3d.vertex.positions.numpy()
    return chassis_scene, chassis_verts, n_verts, n_faces, motor_tm, motor_scene, motor_verts, keepout_scene, keepout_verts


def run_sweep(params: dict) -> list[dict]:
    grid = sweep_grid(params["sweep"])
    print(f"sweep grid: {len(grid)} placements")
    (chassis_scene, chassis_verts, n_verts, n_faces, motor_tm, motor_scene, motor_verts,
     keepout_scene, keepout_verts) = _build_scenes(params)
    print(f"chassis: {n_faces} faces, {n_verts} vertices")

    n_samples = params["sweep"]["samples"]
    clearance_min = params["placement"]["clearance_min"]

    rows = []
    t0 = time.time()
    for i, (x, y, z, lean) in enumerate(grid):
        row = evaluate(
            params, x, y, z, lean,
            chassis_scene, chassis_verts, motor_scene, motor_verts, keepout_scene, keepout_verts,
            n_samples, clearance_min,
        )
        rows.append(row)
        if (i + 1) % 200 == 0:
            print(f"  {i + 1}/{len(grid)} ({time.time() - t0:.1f}s elapsed)")
    print(f"sweep done: {len(grid)} placements in {time.time() - t0:.1f}s")

    artefacts = artefacts_dir()
    (artefacts / "sweep.json").write_text(json.dumps(rows, indent=2), encoding="utf-8")
    print(f"wrote sweep.json ({(artefacts / 'sweep.json').stat().st_size} bytes)")

    mf_min, mf_inside = motor_vs_frame(params, chassis_scene, chassis_verts, motor_scene, motor_tm, n_samples)
    print(f"motor_frame_min: {mf_min} mm, motor_frame_inside: {mf_inside}")

    return rows, mf_min, mf_inside


def summarise(rows: list[dict], params: dict) -> dict:
    xs = sorted(set(r["x"] for r in rows))
    leans = sorted(set(r["lean"] for r in rows))

    per_x_lean = {}
    for x in xs:
        for lean in leans:
            subset = [r for r in rows if r["x"] == x and r["lean"] == lean and r["pass"]]
            if subset:
                ys = sorted(set(r["y"] for r in subset))
                zs = sorted(set(r["z"] for r in subset))
                best = max(subset, key=lambda r: r["min_frame"])
                per_x_lean[(x, lean)] = {
                    "y_range": (min(ys), max(ys)), "z_range": (min(zs), max(zs)),
                    "best_min_frame": best["min_frame"],
                }
            else:
                per_x_lean[(x, lean)] = None

    passing = [r for r in rows if r["pass"]]
    best_overall = max(passing, key=lambda r: r["min_frame"]) if passing else None

    pl = params["placement"]
    defaults_row = None
    for r in rows:
        if (abs(r["x"] - pl["x"]) < 1e-6 and abs(r["y"] - pl["y"]) < 1e-6
                and abs(r["z"] - pl["z"]) < 1e-6 and abs(r["lean"] - pl["lean_deg"]) < 1e-6):
            defaults_row = r
            break

    return {"xs": xs, "leans": leans, "per_x_lean": per_x_lean, "best_overall": best_overall,
            "defaults_row": defaults_row, "n_pass": len(passing), "n_total": len(rows)}


# ---------------------------------------------------------------------------
# Section renders
# ---------------------------------------------------------------------------

def _box_edges_local() -> list[tuple[int, int]]:
    # 8 corners indexed 0-7 as (x in {0,1}, y in {0,1}, z in {0,1}); 12 edges of a box
    return [(0, 1), (2, 3), (4, 5), (6, 7),  # along x
            (0, 2), (1, 3), (4, 6), (5, 7),  # along y
            (0, 4), (1, 5), (2, 6), (3, 7)]  # along z


def _box_corners_local(params: dict) -> np.ndarray:
    mesh = get_shell_mesh(params)
    v = np.asarray(mesh.vertices)
    lo, hi = v.min(axis=0), v.max(axis=0)
    xs, ys, zs = [lo[0], hi[0]], [lo[1], hi[1]], [lo[2], hi[2]]
    return np.array([[x, y, z] for x in xs for y in ys for z in zs])


def render_section(params: dict, plane: str, placement: tuple[float, float, float, float],
                    name: str, mesh_1m_verts: np.ndarray) -> Path:
    from PIL import Image, ImageDraw

    x, y, z, lean = placement
    m = params["motor"]
    k = params["keepout"]
    motor_tm = motor_mesh(params)
    keepout_tm = keepout_mesh(params)
    local_corners = _box_corners_local(params)
    edges = _box_edges_local()
    left_corners = place_vertices(local_corners, x, y, z, lean, "left")
    right_corners = place_vertices(local_corners, x, y, z, lean, "right")

    scale = 1.0
    if plane == "yz":
        slab = mesh_1m_verts[np.abs(mesh_1m_verts[:, 0] - x) <= 100]
        def proj(p):
            return (-p[1], p[2])
        grid_h, grid_v = "y", "z"
    elif plane == "xz":
        slab = mesh_1m_verts[np.abs(mesh_1m_verts[:, 1]) <= 450]
        def proj(p):
            return (p[0], p[2])
        grid_h, grid_v = "x", "z"
    elif plane == "xy":
        slab = mesh_1m_verts[(mesh_1m_verts[:, 2] >= 150) & (mesh_1m_verts[:, 2] <= 700)]
        def proj(p):
            return (p[0], p[1])
        grid_h, grid_v = "x", "y"
    else:
        raise ValueError(plane)

    pts = np.array([proj(p) for p in slab]) if len(slab) else np.zeros((0, 2))
    all_h = [proj(c)[0] for c in left_corners] + [proj(c)[0] for c in right_corners]
    all_v = [proj(c)[1] for c in left_corners] + [proj(c)[1] for c in right_corners]
    if len(pts):
        all_h += pts[:, 0].tolist()
        all_v += pts[:, 1].tolist()
    h_min, h_max = min(all_h) - 50, max(all_h) + 50
    v_min, v_max = min(all_v) - 50, max(all_v) + 50
    W = max(200, int((h_max - h_min) * scale))
    H = max(200, int((v_max - v_min) * scale))
    W, H = min(W, 2000), min(H, 2000)

    img = Image.new("RGB", (W, H), (255, 255, 255))
    draw = ImageDraw.Draw(img)

    def to_px(hv):
        h, v = hv
        return (int((h - h_min) / (h_max - h_min) * W), int(H - (v - v_min) / (v_max - v_min) * H))

    for g in np.arange(np.floor(h_min / 100) * 100, h_max + 100, 100):
        x0, y0 = to_px((g, v_min)); x1, y1 = to_px((g, v_max))
        draw.line([x0, y0, x1, y1], fill=(225, 225, 225))
    for g in np.arange(np.floor(v_min / 100) * 100, v_max + 100, 100):
        x0, y0 = to_px((h_min, g)); x1, y1 = to_px((h_max, g))
        draw.line([x0, y0, x1, y1], fill=(225, 225, 225))

    for p in pts[::max(1, len(pts) // 150000)]:
        px, py = to_px(p)
        if 0 <= px < W and 0 <= py < H:
            draw.point((px, py), fill=(120, 120, 120))

    ox, oy = to_px((0, 0))
    draw.line([ox, 0, ox, H], fill=(255, 0, 0))
    draw.line([0, oy, W, oy], fill=(255, 0, 0))

    for corners, color in ((left_corners, (0, 60, 220)), (right_corners, (0, 60, 220))):
        proj_c = [proj(c) for c in corners]
        for a, b in edges:
            draw.line([to_px(proj_c[a]), to_px(proj_c[b])], fill=color, width=2)

    for tm, color in ((motor_tm, (230, 120, 0)), (keepout_tm, (0, 150, 0))):
        vv = np.asarray(tm.vertices)
        proj_v = np.array([proj(p) for p in vv])
        for i in range(0, len(proj_v), max(1, len(proj_v) // 200)):
            px, py = to_px(proj_v[i])
            if 0 <= px < W and 0 <= py < H:
                draw.ellipse([px - 1, py - 1, px + 1, py + 1], fill=color)

    out = artefacts_dir() / f"section-{plane}-{name}.png"
    img.save(out)
    return out


# ---------------------------------------------------------------------------
# Report
# ---------------------------------------------------------------------------
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

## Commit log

2026-09-09 docs: add project README
    Records the eQuad conversion of a 2012 Suzuki King Quad 400 (LT-A400F) and
    the AI-supported 3D modelling workflow that is the current focus.
    Covers the donor vehicle and its stock driveline ratios, the powertrain as
    purchased, drivetrain sizing from the motor rotor through the internal
    gearbox to the wheels, cooling duct and heatsink sizing, the CAN
    architecture, and the design packages the fabricator will build from.
    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
2026-09-14 docs: add scan-to-CAD options report and scan pipeline plan
    Research report ranking five routes from the Artec scan to a clean CAD
    base, with measured evidence from the scan itself: it is the stripped
    rolling chassis, the full-res export carries the floor, and the frame
    is round tube of two sizes with welded tabs.
    Thrifty plan for the first four pipeline stages (toolsets, condition,
    crop, segment, fit): six work packages, a measured datum procedure with
    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
2026-09-14 feat(thrifty): WP-01 install the mesh toolset
    Pinned .venv-mesh (pymeshlab 2025.7.post1, open3d 0.19.0, trimesh 5.1.0,
    pyransac3d 0.7.0), CloudCompare and MeshLab via winget, config.example.toml,
    and pipeline/common.py (config loading, STL streaming, PNG silhouette,
    circle fit). Smoke-tested: CloudCompare RANSAC recovers a 12.5 mm synthetic
    cylinder at 12.550 mm; pymeshlab sphere decimate/reload round-trips at 500
    faces.
2026-09-14 feat(thrifty): WP-02 install the CAD toolset
    Pinned .venv-cad (build123d 0.11.1, cadquery-ocp-novtk 7.9.3.1.1) and
    .venv-draft (draftwright 0.4.29, its own build123d 0.10.0 and
    cadquery-ocp 7.8.1.1.post1 with vtk), FreeCAD 1.1.3 via winget, and the
    SheetMetal workbench cloned into FreeCAD's user Mod directory. Smoke
    tested: build123d box round-trips through STEP at volume 6000, draftwright
    produces a 59 kB PDF from that STEP, and FreeCAD imports SheetMetalNewUnfolder
    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
2026-09-14 fix(thrifty): WP-03 correct mesh-mutation and rear-axle-crop bugs in condition.py
2026-09-15 fix(thrifty): widen rear-axle bracket and relax cylinder fit threshold
    Adds a 26-29mm tube_radii_mm bracket (owner's config.local.toml, not
    committed) so the rear-axle housing's left side reaches refinement
    instead of being dropped before its fit quality is ever checked.
    Raises CYLINDER_ACCEPT_RMS_MAX from 0.8mm to 1.0mm, recovering 46
    previously-rejected well-supported cylinders (127 -> 173 accepted).
    The housing itself still fails to fit a clean cylinder even under the
    relaxed threshold (rms 1.94mm) - this is a real geometry finding, not
    a threshold problem, and needs a physical calliper/rescan to resolve.
    Re-ran condition.py fresh on the full-res scan to regenerate the datum
    artefacts;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
2026-09-15 docs(thrifty): add chassis interface geometry handover document
    Self-contained HTML summary of the WP-06 fit results for Sam /
    Lakeview Engineering review: the rear-axle housing bracket/threshold
    findings, the ~13mm tube family, and front-flange dowels, each with
    an issue/action breakdown and two real scan-vs-fit comparison images
    (inlined). Asks are scoped to fabrication input only, not physical
    verification - the bike is disassembled and Jeremy is measuring
    directly.
2026-09-15 docs(thrifty): make chassis interface geometry doc readable at 100% zoom
    Base text sized for reading unzoomed on a large screen (18px root,
    rem-scaled headings/body/table text), sheet widened to 1220px max, and
    the two comparison images enlarged accordingly.
2026-09-15 docs(thrifty): redesign chassis interface doc instead of scaling it
    The previous pass (#11) just bumped a root font-size multiplier and
    widened the card - functionally the same as the reader zooming their
    browser, which is what prompted this. This is a real layout change:
    - Explicit px sizes throughout (no root-level scalar), body text
    bumped ~45% (14.5px -> 21px) with a deliberate hierarchy rather
    than uniform scaling.
    - The two comparison images go from a cramped two-column grid to a
    single stacked column at full sheet width, each one much larger.
2026-09-15 docs(thrifty): add battery box plan
    Six work packages under docs/thrifty/2026-09-15-battery-boxes: parametric
    cell and block, sheet enclosure, two-box vehicle assembly on the ISO 8855
    datum, clearance sweep against the scanned frame, mount pickups, and the
    viewer and handover document. Every dimension lives in cad/params.toml;
    placement and lean stay parameters until the plastics are scanned.
2026-09-15 feat(thrifty): WP-01 params, common module, cell and block
    [block.step, cell.step]
2026-09-15 feat(thrifty): WP-02 enclosure
    Body, lid, end plate, partition, compression plate, fuse envelopes,
    grub-screw and cable-exit holes, and the STEP/STL exports, per plan
    section 4.5.
    Two of the plan's literal done-when numbers diverge from what was built,
    both traced to upstream data rather than a modelling defect and logged
    in findings/WP-02.md: the front-column spacer geometry doesn't match
    section 4.4's own worked numbers (computed gap is 0, not p - partition),
    and fuse_envelope (OWNER: confirm) is wider than the fuse bay it's meant
    to sit in. A 20 mm test chamfer also doesn't fit the 3 mm sheet; proven
    instead at 2 mm.
    [box-full.step, box-shell.stl, box.step]
2026-09-15 feat(thrifty): WP-03 vehicle assembly, placement and motor/keep-out
    [assembly.step]
2026-09-16 feat(thrifty): WP-04 canary + owner design corrections, paused
    Clearance canary (controls) passed against the scan. Session then pivoted to
    live placement iteration with the owner via a standalone three.js viewer:
    - motor axis corrected Y -> X (in-line with the prop shafts)
    - motor centre repositioned clear of the frame
    - battery box lean/gap/X position revised several times, settling on a
    hinge-rotation reference (each box pivots about its inner-most edge) that
    the committed placement params reproduce exactly via assembly.py's
    existing origin-based transform
    The formal sweep, sweep-report.md and section renders are not done - the
    owner deprioritised collision-sweep precision in favo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
    [assembly.step]
2026-09-16 docs(thrifty): update battery-boxes plan with 2026-09-17 owner corrections
    Section 4.2's params.toml verbatim block and a new section 4.6a document
    two corrections from the live WP-04 placement session: the motor axis
    (Y -> X, in-line with the prop shafts) and the box rotation reference
    (each box pivots about its inner-most edge, not the local origin -
    assembly.py still implements origin-based rotation, so the committed
    placement values are back-solved equivalents, verified against
    assembly.py's own inboard_gap_at_floor output).
    Validated with Test-ThriftyPlan.ps1 (0 failures, 8 checks).
2026-09-17 feat(thrifty): WP-04 done - sweep re-run against corrected placement, 0/525 pass
    Finished cad/clearance.py: sweep grid, full sweep, summary, section renders
    and sweep-report.md (items 5-11). The [sweep] grid was re-centred on the
    owner's 2026-09-17 placement correction (the original grid predates it and
    doesn't bracket the current design point).
    Result: 525 placements swept, zero pass. The current committed [placement]
    does not clear the frame anywhere in the swept neighbourhood - the
    least-bad point still has 15580 frame points inside the box. This is a
    real geometry finding, not a script defect; recorded in findings/WP-04.md
    and status/WP-04.md for the owner to resolve.
    [clearance.py]
2026-09-17 chore(thrifty): WP-05 blocked - placement not confirmed clear of frame
    The WP-04 sweep (525 placements re-centred on the current [placement])
    found zero passing points; the committed placement does not clear the
    frame anywhere nearby. Mount pickups need a placement the sweep confirms
    is clear, which is an owner decision, not something this session can
    make.
2026-09-17 feat(thrifty): WP-05 done - mount pickups against the current placement
    cad/mounts.py lists every fitted frame cylinder (173 accepted, all regions
    of interfaces.json) and RANSAC plane (48 with support > 1500 in
    primitives-engine-bay.json) within 120 mm of either placed battery box:
    104 kept, sorted by distance, each with a nearest face derived from the
    section 4.6 transform and each plane row carrying "calliper before
    drilling".
    Runs against the committed [placement] (743.2, 39.2643, 440.4765,
    lean 82 deg) per owner direction 2026-09-17: correct for now, with
    chassis modifications and further adjustment expected before the sweep
    needs to pass.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
    [assembly.step]
2026-09-17 feat(thrifty): WP-06 batch 1 - cad/viewer.py and viewer.html
2026-10-05 docs(thrifty): add WP7 to the battery-boxes plan - named STEP bodies and Fusion import pack
    Adds section 4.10 (labels and colours for every STEP body), section 4.11
    (datum marker and Fusion import workflow document), section 5.9 (measured
    constraints), WP7 with its starter prompt, and the matching scope, artefact
    table, owner-action and collision entries.
2026-10-07 feat(thrifty): WP-07 batch 1 - cell and block named and coloured; box-full check blocked
    [block.step, cell.step]
2026-10-07 feat(thrifty): WP-07 batch 2 - every STEP body named and coloured
    [assembly.step, box-full.step, box.step]
2026-10-07 feat(thrifty): WP-07 done - Fusion import pack with datum marker
    [datum-marker.step]
